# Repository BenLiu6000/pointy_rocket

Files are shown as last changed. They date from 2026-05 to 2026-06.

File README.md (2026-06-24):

# 🚀 Pointy Rocket V1

**Pointy Rocket** is an actively stabilised model-scale rocket developed by the Engineering Society of Castleknock College (SVCC). It uses **Thrust Vector Control (TVC)** — the same technique used in orbital-class rockets — to actively stabilise the vehicle in flight.

The project spans custom PCB hardware design, embedded flight firmware, and a high-fidelity physics simulation, all living in this repository.

---

> **An SVCC Project with support from RS Components**
> RS Logo&nbsp;&nbsp;&nbsp;&nbsp;&nbsp;&nbsp;&nbsp;&nbsp;&nbsp;&nbsp;&nbsp;&nbsp;RS Logo

---

## Authors

- James Harcourt
- Basil Amin
- Ashkan Samali
- Feargal Browne
- Ben Liu
- Ryan Doran

---

## Project Overview

| Component | Details |
|---|---|
| Stabilisation | 2-axis Thrust Vector Control (TVC) via servo-gimballed motor mount  |
| Motors | 4× Estes D12 (clustered) |
| Microcontroller | Teensy 4.1 (NXP i.MX RT1062, Cortex-M7 @ 600 MHz) |
| IMU | MPU6050 (6-axis accelerometer + gyroscope, I2C) |
| Altimeter | MPL3115A2 barometric altimeter |
| Data Logging  | SD card (SPI) |
| Recovery | Parachute deployment |

---

## Repository Structure

```
pointy_rocket/
├── Dictator_Flight_Firmware/   # Main embedded flight firmware (Teensy 4.1 / PlatformIO)
├── Firmware_test/              # Firmware testing scripts and utilities
├── hardware/                   # KiCad PCB schematic & layout
│   └── pcb/
│       └── Pointy R1 Flight controller/
│           ├── *.kicad_sch
│           ├── *.kicad_pcb
│           ├── symbols.kicad_sym
│           └── footprints.pretty/
├── simulation/                 # Python flight simulation suite
│   ├── rocket_sim.py           # Full 6-DOF 3D simulation (RK4 + Quaternions)
│   ├── tvc_sim.py              # TVC-controlled flight engine
│   ├── rocketpy_engine.py      # RocketPy aerodynamics integration
│   ├── rocketpy_adapter.py     # Hybrid engine orchestrator
│   ├── motor_curve.py          # Thrust curve parser (.eng / .rse / .csv)
│   ├── motor_sweep.py          # Motor configuration parameter sweep
│   ├── gui_server.py           # Browser-based TVC simulator GUI
│   ├── plots.py                # Standalone matplotlib figure generator
│   ├── pygame_simulation.py    # Pygame visualisation
│   ├── requirements.txt
│   └── simulation_results.png
├── Media/                      # Logos and media assets
├── Pointy R1 Flight controller.csv  # BOM / component list
├── sim_specs.txt               # Simulation variable reference
└── .gitignore
```

---

## Firmware

The flight computer runs on a **Teensy 4.1**, programmed via PlatformIO with the Arduino framework. The firmware reads IMU data, runs a PID controller, and drives the two TVC servos in real time.

### Hardware

| Component | Details |
|---|---|
| Microcontroller | Teensy 4.1 (NXP i.MX RT1062, Cortex-M7 @ 600 MHz) |
| IMU | MPU6050 (6-axis accelerometer + gyroscope, I2C)  |
| Altimeter | MPL3115A2 barometric altimeter |
| Actuation | 2× Servo (dual-axis TVC gimbal) |
| Data Logging | SD card (SPI) |
| Power | AMASS XT60 connector |
| Ignition | N-MOSFET (D2PAK) motor ignition circuit |

### Dependencies

| Library | Version  |
|---|---|
| `arduino-libraries/Servo` | `^1.3.0` |
| `electroniccats/MPU6050`  | `^1.4.4` |
| `arduino-libraries/SD` | `^1.3.0` |

### Build & Flash

**Prerequisites:** [PlatformIO](https://platformio.org/) (CLI or VS Code extension)

```bash
# Clone the repo
git clone https://github.com/BasilAmin/pointy_rocket.git
cd pointy_rocket/Dictator_Flight_Firmware

# Build
pio run

# Flash to Teensy (press the button on the board if needed)
pio run --target upload

# Open serial monitor
pio device monitor
```

---

## Hardware / PCB

The custom flight controller PCB is designed in **KiCad** and lives in `hardware/pcb/Pointy R1 Flight controller/`. Custom symbols and footprints are included for:

- Teensy 4.1 (form-factor reference)
- MPU6050 breakout (GY-521 module)
- MPL3115A2 barometric altimeter
- AMASS XT60 power connector
- N-MOSFET (D2PAK) motor ignition circuit
- Tactile and slide switches
- Passive components (diode, SOT-23 transistor)

To open the design, install [KiCad 7+](https://www.kicad.org/) and open `Pointy R1 Flight controller.kicad_pro`.

---

## Simulation

The simulation suite models the full flight from ignition through parachute landing. It uses a hybrid approach combining the trusted aerodynamics of **RocketPy** with a custom in-house **TVC 6-DOF engine**.

### Architecture

Because Pointy Rocket is a finless TVC rocket (unstable by design), a purely passive simulation cannot fly it. The two engines are combined to play to each other's strengths:

- **RocketPy** (`rocketpy_engine.py`) provides trusted aerodynamics: Barrowman centre of pressure, static margin, a real atmosphere model. It cannot model thrust vectoring, so it cannot fly the rocket passively.
- **The in-house TVC sim** (`tvc_sim.py`) flies the actively steered rocket (quaternion 6-DOF, RK4, PID gimbal), using RocketPy's centre of pressure and drag values instead of a rough analytic estimate.

`rocketpy_adapter.py` orchestrates both and returns side-by-side results.

### Setup

```bash
cd simulation
python -m venv .venv && source .venv/bin/activate   # Windows: .venv\Scripts\activate
pip install -r requirements.txt
```

Requirements: `numpy`, `matplotlib`, `rocketpy` (which pulls in `scipy` and `netCDF4`).

### TVC Simulator GUI

A browser-based GUI wraps both flight engines and lets you upload or fetch motor files, import body geometry, and view results interactively.

```bash
cd simulation
python gui_server.py
```

Open `http://127.0.0.1:8765`. Each run renders a **matplotlib** figure (altitude, thrust curve, TVC gimbal angles, speed/mass) shown below the live chart with a PNG download link.

The same figure can be produced from the command line:

```bash
python plots.py path/to/motor.eng    # writes matplotlib_results.png
```

### 6-DOF Flight Simulation

`rocket_sim.py` implements a full **6 Degrees of Freedom** rigid-body simulation:

- **RK4 numerical integration** for accurate state propagation
- **Quaternion-based attitude representation** (no gimbal lock)
- **PID controller** for dual-axis TVC stabilisation
- **Dynamic mass model** — propellant mass decreases with cumulative impulse
- **High-fidelity D12 thrust curve** (4× scaled cluster, from verified RASP data)
- **Aerodynamic drag** with wind shear model
- **Automatic parachute deployment** on descent

#### PID Controller Parameters

| Gain | Value |
|---|---|
| Kp | 0.8 |
| Kd | 1.5 |
| Ki | 0 |
| Max gimbal angle | ±8° |

```bash
python rocket_sim.py
```

Outputs a 4-panel plot (`simulation_results.png`) showing:

- 3D flight trajectory
- Altitude vs. time
- Dual-axis TVC gimbal angles
- Dynamic mass and thrust profile

### Motor Configuration Sweep

`motor_sweep.py` sweeps across 1–4 motor configurations to compare predicted performance across different cluster sizes.

```bash
python motor_sweep.py
```

---

## Language Breakdown

| Language | Share  |
|---|---|
| C++ | 81.2%  |
| Python | 9.7% |
| C | 6.0% |
| JavaScript | 1.2% |
| Processing | 0.9% |
| HTML | 0.6% |
| Other | 0.4% |

---

## License

MIT License — © 2026 Basil Amin. See [LICENSE](firmware/LICENSE) for details.
## License

MIT License — © 2026 Basil Amin. See [LICENSE](firmware/LICENSE) for details.

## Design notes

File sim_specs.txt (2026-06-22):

Fundamental Simulation variables:
- Velocity
- Vertical Velocity
- Horizontal Velocity
- Vertical displacement
- Horizontal displacement
- Gravitational constant (9.802m/s^2)
- Time elapsed/Time taken
- Acceleration
- Mass
- Initial Thrust Force
- Normal Thrust Force
- Motor Burn Time

This is excluding the control system and strictly considers a point mass being propelled up. It does not really take much into consideration but is fundamental

mass = 0.891;        % kg

Iyy = 0.286;        % kg*m^2

CG = 0.518;         % m from nose

nozzle = 0.855;     % m from nose

back = 0.801;      % m

lever_arm = nozzle - CG;

%% TVC

max_gimbal = 8*pi/180;   % radians

servo_tau = 0.09;        % seconds

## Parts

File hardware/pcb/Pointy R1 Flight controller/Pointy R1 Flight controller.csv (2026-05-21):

Reference | Qty | Value | DNP | Exclude from BOM | Exclude from Board | Footprint | Datasheet
C1 | 1 | 10uF |  |  |  | Capacitor_SMD:C_0805_2012Metric | ~
C2 | 1 | 1uF |  |  |  | Capacitor_SMD:C_0805_2012Metric | ~
C3 | 1 | 100nF |  |  |  | Capacitor_SMD:C_0805_2012Metric | ~
D1 | 1 | 1N5822 |  |  |  | footprints:DIOAD1990W125L900D530
D2,D3,D4 | 3 | 1N4007 |  |  |  | footprints:P1_DO-41 | https://diotec.com/de/produktliste/D.html
IC1 | 1 | TEENSY_4.1 |  |  |  | footprints:TEENSY41
J3 | 1 | XT60-M |  |  |  | footprints:AMASS_XT60-M
LED1 | 1 | COM-16347 |  |  |  | footprints:COM-16347_SPK | COM-16347
LS1 | 1 | CMI-1295-0585T |  |  |  | footprints:CUI_CMI-1295-0585T
M1,M2 | 2 | Motor_Servo |  |  |  | Connector_PinHeader_2.54mm:PinHeader_1x03_P2.54mm_Vertical | http://forums.parallax.com/uploads/attachments/46831/74481.png
P1,P2,P3,P4 | 4 | 282837-2 |  |  |  | footprints:TE_282837-2
Q1,Q2,Q3 | 3 | IRLZ44NSTRLPBF |  |  |  | footprints:NMOSGDS_D2PAK_INF | https://www.infineon.com/dgdl/irlz44nspbf.pdf?fileId=5546d462533600a40153567221272727
R2,R3,R5,R7 | 4 | 470 |  |  |  | Resistor_SMD:R_0805_2012Metric | ~
R8 | 1 | 10k |  |  |  | Resistor_SMD:R_0805_2012Metric | ~
R9 | 1 | 4.7k |  |  |  | Resistor_SMD:R_0805_2012Metric | ~
S2 | 1 | TS02-66-70-BK-100-LCR-D |  |  |  | footprints:SW_TS02-66-70-BK-100-LCR-D
U1 | 1 | L7805CV |  |  |  | footprints:TO255P1040X460X1968-3
U2 | 1 | GY-521 |  |  |  | footprints:MODULE_GY-521
U3 | 1 | MPL3115A2 |  |  |  | footprints:MPL3115A2

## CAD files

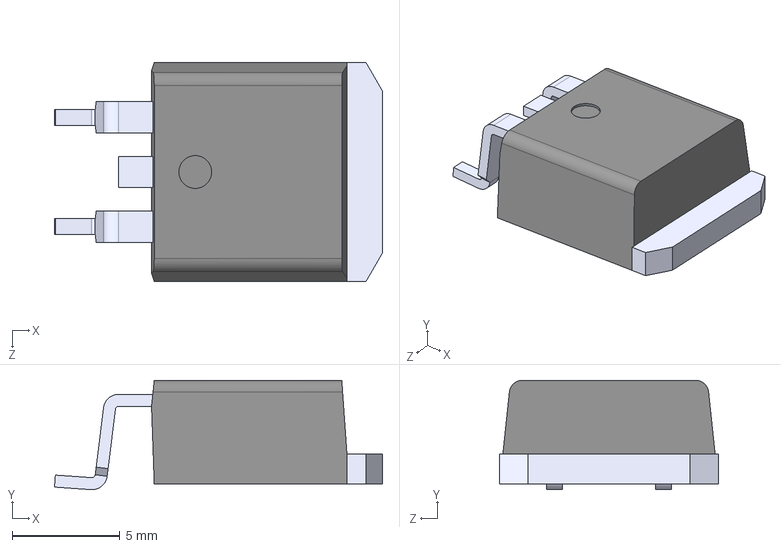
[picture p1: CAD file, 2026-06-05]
hardware/pcb/Pointy R1 Flight controller/3d Models/IRLZ44NSTRLPBF.STEP
15.2 x 5.08 x 10.2 mm

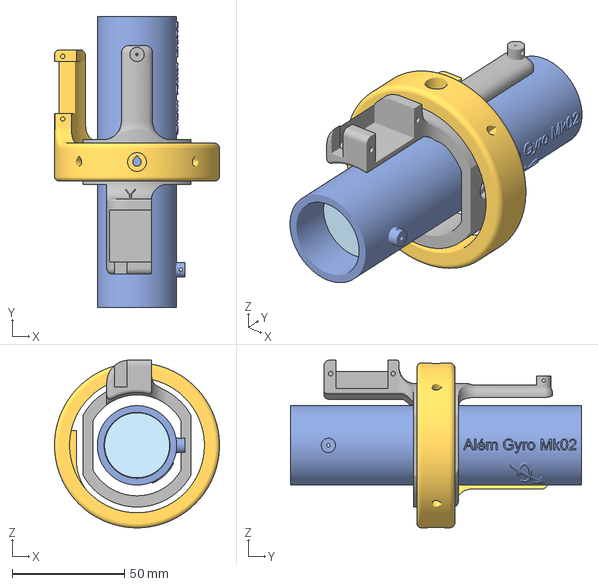
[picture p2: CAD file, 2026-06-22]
hardware/TVC_mount.step
73.6 x 130.0 x 74.8 mm
Estes F15

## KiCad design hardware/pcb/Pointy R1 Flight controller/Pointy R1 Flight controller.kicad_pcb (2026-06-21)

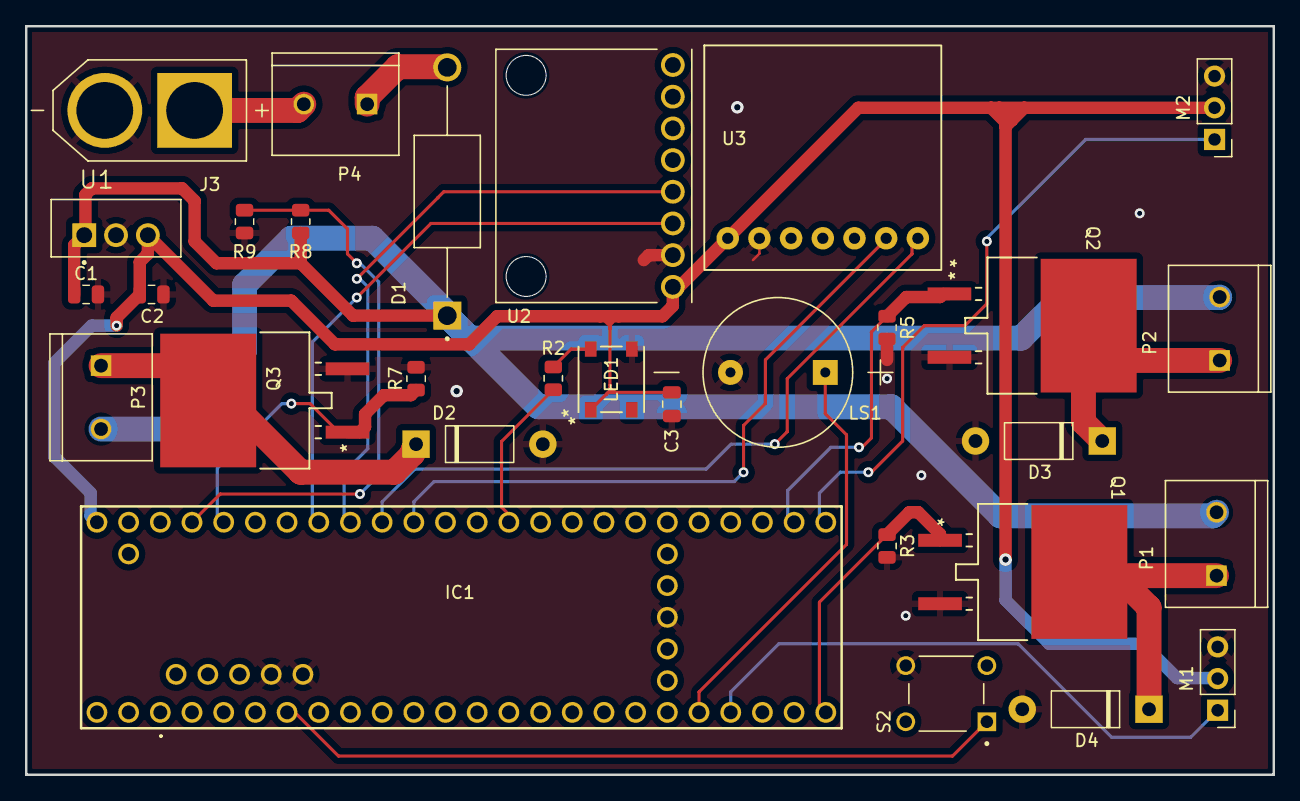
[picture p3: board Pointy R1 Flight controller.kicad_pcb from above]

Board: 2 copper layers, 100.0 x 60.0 mm, 30 parts (0 on the bottom side), 22 nets.

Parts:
C1: 10uF; C_0805_2012Metric
C2: 1uF; C_0805_2012Metric
C3: 100nF; C_0805_2012Metric
D1: 1N5822; DIOAD1990W125L900D530
D2, D3, D4: 1N4007; P1_DO-41
IC1: TEENSY_4.1; TEENSY41
J3: XT60-M; AMASS_XT60-M
LED1: COM-16347; COM-16347_SPK
LS1: CMI-1295-0585T; CUI_CMI-1295-0585T
M1, M2: Motor_Servo; PinHeader_1x03_P2.54mm_Vertical
P1, P2, P3, P4: 282837-2; TE_282837-2
Q1, Q2, Q3: IRLZ44NSTRLPBF; NMOSGDS_D2PAK_INF
R2, R3, R5, R7: 470; R_0805_2012Metric
R8: 10k; R_0805_2012Metric
R9: 4.7k; R_0805_2012Metric
S2: TS02-66-70-BK-100-LCR-D; SW_TS02-66-70-BK-100-LCR-D
U1: L7805CV; TO255P1040X460X1968-3
U2: GY-521; MODULE_GY-521
U3: MPL3115A2

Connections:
7.4V: C1.1, D1.C, P1.2, P2.2, P3.2, R8.1, U1.1 (INPUT)
+5V: C2.1, C3.1, IC1.55 (VIN_(3.6_TO_5.5_VOLTS)), LED1.1 (VDD), M1.2 (+), M2.2 (+), U1.3 (OUTPUT), U2.VCC, U3.1 (Vin)
BAT+: J3.P (POS), P4.2
BUZ: IC1.28 (RX7), LS1.P
GND: C1.2, C2.2, C3.2, D2.2 (C), D3.2 (C), D4.2 (C), IC1.45 (GND_1), IC1.48 (GND_2), IC1.49 (GND_3), J3.N (NEG), LED1.3 (VSS), LS1.N, M1.3 (-), M2.3 (-), Q1.3 (S), Q2.3 (S), Q3.3 (S), R3.2, R5.2, R7.2, R9.1, S2.4, U1.2 (GROUND), U2.GND, U3.2 (GND)
LED: IC1.13 (SCK), R2.2
unnamed: D1.A, P4.1
unnamed: D2.1 (A), P3.1, Q3.2 (D)
unnamed: D3.1 (A), P2.1, Q2.2 (D)
unnamed: D4.1 (A), P1.1, Q1.2 (D)
unnamed: LED1.4 (DIN), R2.1
PY1: IC1.32 (OUT1B), Q1.1 (G), R3.1
PY2: IC1.34 (RX8), Q2.1 (G), R5.1
PY3: IC1.22 (A8), Q3.1 (G), R7.1
SCL: IC1.19 (A5), U2.SCL
SCL1: IC1.16 (A2), U3.6 (SCL)
SDA: IC1.18 (A4), U2.SDA
SDA1: IC1.17 (A3), U3.7 (SDA)
SW: IC1.5 (IN2), S2.1
TVC_X: IC1.29 (TX7), M1.1 (PWM)
TVC_Y: IC1.33 (MCLK2), M2.1 (PWM)
VOL: IC1.23 (A9), R8.2, R9.2

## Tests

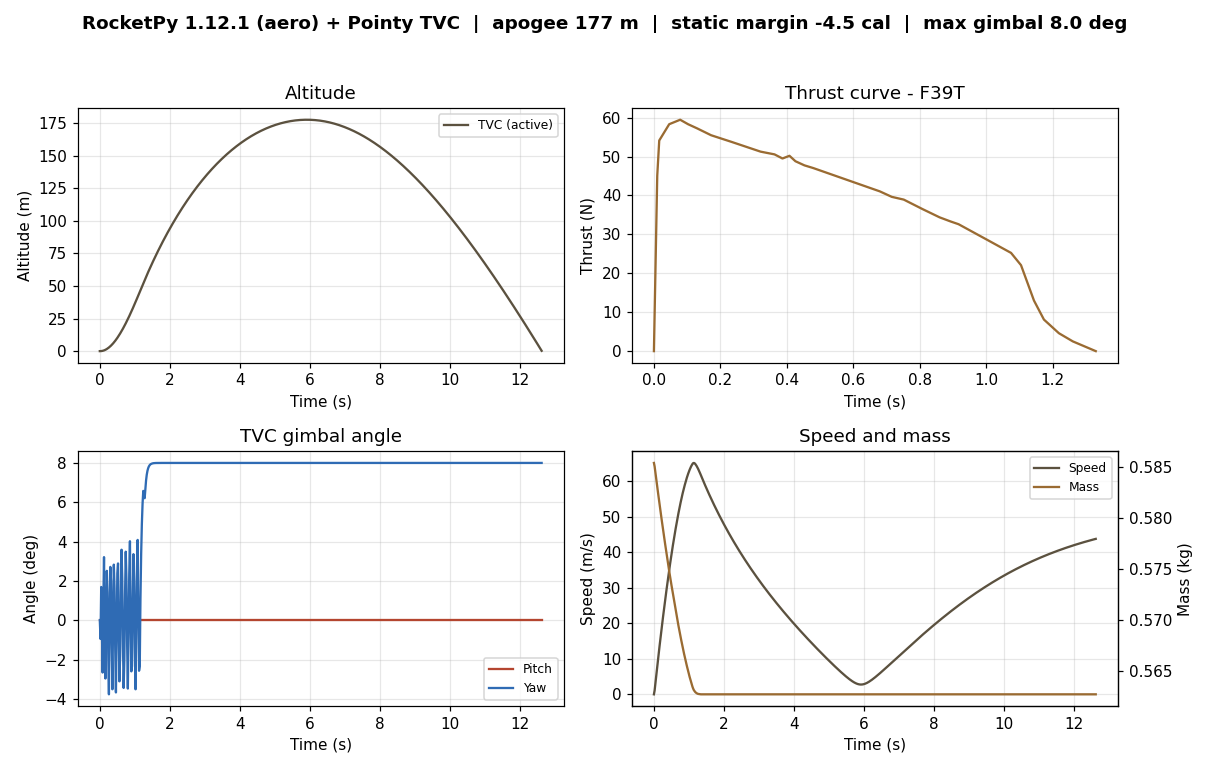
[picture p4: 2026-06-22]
simulation/matplotlib_results.png

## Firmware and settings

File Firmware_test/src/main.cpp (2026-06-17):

//THE DICTATOR TEST FIRMWARE
//rn it only tests: servos, IMU, state indication

//Dependencies
#include <Arduino.h>
#include <Servo.h>
#include <MPU6050.h>
#include <I2Cdev.h>
#include <Adafruit_MPL3115A2.h>
#include <SD.h>
#include <Adafruit_NeoPixel.h>
#include <Wire.h>

#define TVCX 29
#define TVCY 33

#define pyro1 32
#define pyro2 34
#define pyro3 22



Adafruit_NeoPixel pixel(1, 13, NEO_GRB + NEO_KHZ800);

int buzzer = 28;

Servo tvcx;
Servo tvcy;

MPU6050 imu;
int16_t ax, ay, az;
int16_t gx, gy, gz;



void setup(){

pinMode(pyro1, OUTPUT);
pinMode(pyro2, OUTPUT);
pinMode(pyro3, OUTPUT);

digitalWrite(pyro1, LOW);
digitalWrite(pyro2, LOW);
digitalWrite(pyro3, LOW);

  /*--Start I2C interface--*/
#if I2CDEV_IMPLEMENTATION == I2CDEV_ARDUINO_WIRE
Wire.begin(); 
#elif I2CDEV_IMPLEMENTATION == I2CDEV_BUILTIN_FASTWIRE
Fastwire::setup(400, true);
#endif

Serial.begin(115200);
Serial.println("Starting avionics testing");
delay(500);

Serial.print("Testing State Indication");
pixel.begin();
pixel.show(); // Initialize to 'off'

pixel.setPixelColor(0, pixel.Color(255, 0, 0)); 
pixel.show();
delay(1000);
  
  // Set pixel 0 to Blue
pixel.setPixelColor(0, pixel.Color(0, 0, 255));
pixel.show();
delay(1000);

tone(buzzer, 3000, 500); 

delay(500);
Serial.println("State Indication complete");
Serial.println("Testing TVC Servos");

tvcx.attach(TVCX);
tvcy.attach(TVCY);

for(int i = 0; i <= 180; i++){
    tvcx.write(i);
    tvcy.write(i);
    delay(10);
}

for(int i = 180; i >= 0; i--){
    tvcx.write(i);
    tvcy.write(i);
    delay(10);
}

Serial.println("TVC Servos Complete! Starting IMU testing");
delay(500);

imu.initialize();
 Serial.println("Testing MPU6050 connection...");
  if(imu.testConnection() ==  false){
    Serial.println("MPU6050 connection failed");
    while(true);
  }
  else{
    Serial.println("MPU6050 connection successful");
  }

  /* Use the code below to change accel/gyro offset values. Use MPU6050_Zero to obtain the recommended offsets */ 
  Serial.println("Updating internal sensor offsets...\n");
  imu.setXAccelOffset(0); //Set your accelerometer offset for axis X
  imu.setYAccelOffset(0); //Set your accelerometer offset for axis Y
  imu.setZAccelOffset(0); //Set your accelerometer offset for axis Z
  imu.setXGyroOffset(0);  //Set your gyro offset for axis X
  imu.setYGyroOffset(0);  //Set your gyro offset for axis Y
  imu.setZGyroOffset(0);  //Set your gyro offset for axis Z
  /*Print the defined offsets*/
  Serial.print("\t");
  Serial.print(imu.getXAccelOffset());
  Serial.print("\t");
  Serial.print(imu.getYAccelOffset()); 
  Serial.print("\t");
  Serial.print(imu.getZAccelOffset());
  Serial.print("\t");
  Serial.print(imu.getXGyroOffset()); 
  Serial.print("\t");
  Serial.print(imu.getYGyroOffset());
  Serial.print("\t");
  Serial.print(imu.getZGyroOffset());
  Serial.print("\n");


  Serial.println("Printing accelerometer and Gyroscoping values (25 sets)");
  for(int i = 0; i <= 25; i++ ){

    imu.getMotion6(&ax, &ay, &az, &gx, &gy, &gz);
    Serial.print("a/g:\t");

Serial.print("AX:");
Serial.print(ax);
Serial.print("\tAY:");
Serial.print(ay);
Serial.print("\tAZ:");
Serial.print(az);
Serial.print("\tGX:");
Serial.print(gx);
Serial.print("\tGY:");
Serial.print(gy);
Serial.print("\tGZ:");
Serial.println(gz);
  }

  delay(1000);

  Serial.println("Finally, testing the pyrochannels");

  delay(1000);
  Serial.println("PYRO 1 ON");
  digitalWrite(pyro1, HIGH);
  delay(2000);
  digitalWrite(pyro1, LOW);
  Serial.println("PYRO 1 OFF");

    delay(1000);
  Serial.println("PYRO 2 ON");
  digitalWrite(pyro2, HIGH);
  delay(2000);
  digitalWrite(pyro2, LOW);
  Serial.println("PYRO 2 OFF");

    delay(1000);
  Serial.println("PYRO 3 ON");
  digitalWrite(pyro3, HIGH);
  delay(2000);
  digitalWrite(pyro3, LOW);
  Serial.println("PYRO 3 OFF");

  
  Serial.println("TESTING COMPLETE");

    }



void loop(){

}

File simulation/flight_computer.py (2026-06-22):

"""Software-in-the-loop model of the Pointy Rocket flight computer.

This is the realistic GNC chain that the in-flight sim drives instead of giving
the controller perfect truth:

    true motion -> MPU6050 (noise/bias/quantisation) -> attitude estimator
                -> discrete PID -> servo (slew/resolution/lag) -> gimbal

Hardware modelled from the actual board/firmware (``Firmware_test/src/main.cpp``):
MPU6050 read with ``getMotion6`` at its defaults (+/-2 g, +/-250 deg/s, 16-bit),
and two hobby servos driven by the Arduino ``Servo`` library (1 deg write
resolution) on the TVC gimbal.

Key physics constraint that drives the estimator design: in flight a rocket's
accelerometer does NOT see gravity (under thrust it reads thrust along the body
axis; in coast it is in free fall and reads ~0). So attitude is propagated by
integrating the gyro, with the accelerometer used only on the pad to set the
initial attitude and to calibrate the gyro bias. Residual gyro bias therefore
drives attitude drift - the dominant real-world error, which this model exposes.
"""

from __future__ import annotations

import math
from collections import deque
from dataclasses import dataclass, field

import numpy as np

from quaternions import (
    conjugate,
    normalize_quaternion,
    quaternion_between,
    quaternion_from_rotvec,
    quaternion_multiply,
    rotate_vector,
)

GRAVITY = 9.80665


@dataclass
class FlightComputerParams:
    # Loop timing
    control_rate_hz: float = 100.0
    loop_latency_s: float = 0.006          # sense -> compute -> actuate transport delay
    pad_duration_s: float = 2.0            # time on the rail used to calibrate

    # MPU6050 (datasheet-derived; defaults match the firmware's initialize())
    gyro_range_dps: float = 250.0
    gyro_lsb_per_dps: float = 131.0
    gyro_noise_dps: float = 0.05           # white noise RMS
    gyro_bias_sigma_dps: float = 3.0       # per-flight constant bias (uncalibrated chip)
    accel_range_g: float = 2.0
    accel_lsb_per_g: float = 16384.0
    accel_noise_g: float = 0.008
    accel_bias_sigma_g: float = 0.02

    # Controller (gains come from the GUI specs; mirrored onto the Teensy)
    kp: float = 0.8
    kd: float = 1.5
    ki: float = 0.0
    max_gimbal_rad: float = math.radians(8.0)
    integral_limit: float = 0.5
    # Feedback signs per axis (proportional/integral share a sign; derivative its own).
    # Determined empirically (sign sweep) so the loop drives tilt toward vertical
    # during powered flight. The damping sign is asymmetric between the pitch and
    # yaw channels because the body-rate axes map oppositely to the two tilt
    # directions through the gimbal/cross-product geometry.
    sign_prop_pitch: float = -1.0
    sign_der_pitch: float = -1.0
    sign_prop_yaw: float = -1.0
    sign_der_yaw: float = 1.0

    # Servo + linkage (gimbal-referred: depends on servo speed and the linkage ratio)
    servo_slew_dps: float = 400.0          # max gimbal rate
    servo_resolution_deg: float = 0.5      # gimbal command quantisation (Servo.write is 1 deg at the horn)
    servo_tau_s: float = 0.02              # first-order lag
    servo_deadband_deg: float = 0.0


class MPU6050:
    """MPU6050 measurement model: per-flight bias + white noise + range clip + LSB quantisation."""

    def __init__(self, rng, params):
        self.rng = rng
        self.gyro_range = math.radians(params.gyro_range_dps)
        self.gyro_lsb_per_rad = params.gyro_lsb_per_dps / math.radians(1.0)
        self.gyro_noise = math.radians(params.gyro_noise_dps)
        self.accel_range = params.accel_range_g * GRAVITY
        self.accel_lsb_per_ms2 = params.accel_lsb_per_g / GRAVITY
        self.accel_noise = params.accel_noise_g * GRAVITY
        # Constant biases drawn once per flight.
        self.gyro_bias = rng.normal(0.0, math.radians(params.gyro_bias_sigma_dps), 3)
        self.accel_bias = rng.normal(0.0, params.accel_bias_sigma_g * GRAVITY, 3)

    @staticmethod
    def _quantize(value, lsb_per_unit, limit):
        clipped = np.clip(value, -limit, limit)
        return np.round(clipped * lsb_per_unit) / lsb_per_unit

    def read_gyro(self, true_rate_body):
        raw = true_rate_body + self.gyro_bias + self.rng.normal(0.0, self.gyro_noise, 3)
        return self._quantize(raw, self.gyro_lsb_per_rad, self.gyro_range)

    def read_accel(self, specific_force_body):
        raw = specific_force_body + self.accel_bias + self.rng.normal(0.0, self.accel_noise, 3)
        return self._quantize(raw, self.accel_lsb_per_ms2, self.accel_range)


class AttitudeEstimator:
    """Gyro-integration attitude estimator with on-pad calibration.

    On the pad the accelerometer sees gravity, so it initialises attitude and the
    averaged gyro gives the bias estimate. In flight the quaternion is propagated
    purely from the bias-corrected gyro (the accelerometer is not a valid gravity
    reference once airborne).
    """

    def __init__(self):
        self.q = np.array([1.0, 0.0, 0.0, 0.0])
        self.bias = np.zeros(3)
        self._gyro_sum = np.zeros(3)
        self._accel_sum = np.zeros(3)
        self._samples = 0
        self.calibrated = False

    def calibrate_sample(self, gyro, accel):
        self._gyro_sum += gyro
        self._accel_sum += accel
        self._samples += 1

    def finalize_calibration(self):
        if self._samples > 0:
            self.bias = self._gyro_sum / self._samples
            mean_accel = self._accel_sum / self._samples
            # mean_accel is the measured gravity-up direction in the body frame;
            # rotate it to world +Y to recover the body->world attitude.
            self.q = quaternion_between(mean_accel, np.array([0.0, 1.0, 0.0]))
        self.calibrated = True

    def update(self, gyro, accel, dt):
        rate = gyro - self.bias
        self.q = normalize_quaternion(quaternion_multiply(self.q, quaternion_from_rotvec(rate * dt)))
        return self.q, rate
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

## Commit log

2026-05-21 Updated PCB files to conform with DFM and regenerated gerbers. PCB ready for manufacture
    [Pointy R1 Flight controller-B_Cu.gbl, Pointy R1 Flight controller-B_Mask.gbs, Pointy R1 Flight controller-B_Paste.gbp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]
2026-05-24 Simulation update
    simulation is finished, now only need to find optimal coefficient values for the PID controller
2026-06-05 Added 3d Models to PCB for teensy + Mosfets
    [IRLZ44NSTRLPBF.STEP, Pointy R1 Flight controller.csv, Pointy R1 Flight controller.kicad_pcb]
2026-06-17 Add files via upload
    Added Test firmware for: IMU, Servos, Pyros and state indication
2026-06-17 Add files via upload
    Fixed flight firmware directory
    [main.cpp]
2026-06-17 Removed Servo libraries. Teensy bundles libs for servo already
2026-06-21 Added rocketpy gui and sim, files uploadable by ork from openroccket. Calculates: CG PG CP Apogee Burnout Etc.
    [Pointy R1 Flight controller.kicad_pcb]
2026-06-21 Integrate RocketPy for trusted aerodynamics alongside the TVC sim
    The GUI was scaffolded for RocketPy but never actually called it - results
    relied on a rough analytic CP estimate while the page mislabelled itself
    "Running RocketPy". This wires in RocketPy 1.12.1 as the aerodynamics engine
    and keeps the in-house sim for the actively steered (TVC) flight.
    - rocketpy_engine.py: builds Environment + GenericMotor + Rocket from the
    .ork-derived specs and motor curve; returns Barrowman CP, static margin
    and (only when statically stable) a passive trajectory. A finless TVC
    rocket is unstable by design and RocketPy's solver stalls on it, so the
    passive flight is gated on stability and skipp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
2026-06-21 Add flight-computer-in-the-loop, fix TVC control sign, add Monte Carlo
    The TVC sim previously steered with perfect knowledge and always launched
    perfectly vertical, which hid a latent control bug. This replaces the inner
    loop with a realistic flight computer and adds dispersion analysis.
    Flight computer (flight_computer.py, new):
    - MPU6050 sensor model matched to the hardware (+/-2 g, +/-250 deg/s, 16-bit
    quantisation) with per-flight bias and white noise.
    - Gyro-integration attitude estimator with on-pad calibration. In flight a
    rocket's accelerometer cannot sense gravity, so it is used only on the pad to
    set initial attitude and gyro bias - this is the reference al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
    [flight_computer.py]
